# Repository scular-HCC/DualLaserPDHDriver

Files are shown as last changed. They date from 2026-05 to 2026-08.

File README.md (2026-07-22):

# Dual-Laser PDH Driver

**A precision two-channel controller for 1550 nm DFB butterfly lasers — a differential optical thermometer built as a 3U Eurocard instrument.**

Each channel provides low-noise constant-current laser drive, a bipolar linear TEC temperature controller, RF frequency modulation, and a synchronous-demodulation Pound–Drever–Hall lock that holds the laser to the side of an optical resonance. Lasers A and B lock to their own fringe of a shared reference cavity; the beat frequency between them, Δν = S·(T_B − T_A) with S ≈ 2 GHz/K, is a ratiometric measurement in which slow common-mode drift cancels.

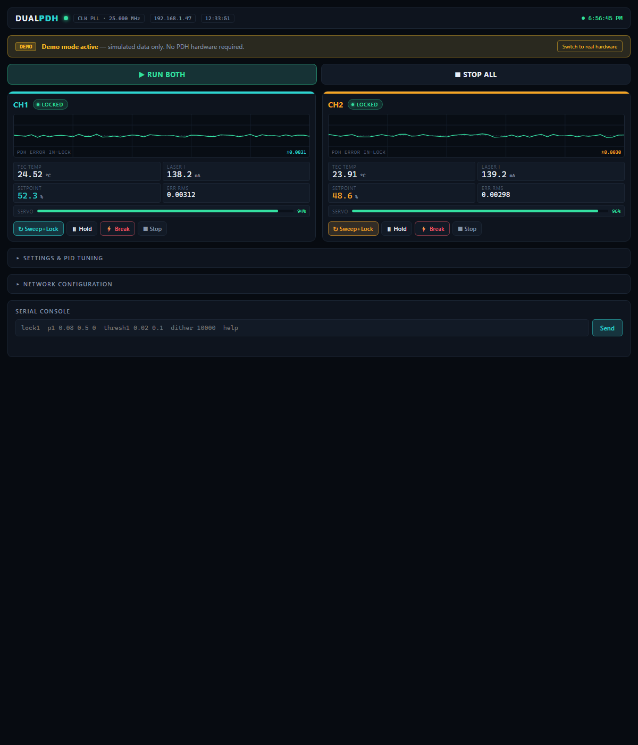
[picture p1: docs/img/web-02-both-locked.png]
Web dashboard — both channels locked


## Highlights

| | |
|---|---|
| **2×** | 1550 nm DFB laser channels |
| **≈2 GHz/K** | beat sensitivity |
| **4–40 nK** | 60 s stability (equivalent-kelvin Allan deviation) |
| **±2.5 A** | bipolar linear TEC per channel |
| **8-slot** | 3U passive backplane, card-based architecture |

The RF analog-derivative lock this hardware runs targets the ≈4–11 nK regime, limited primarily by the laser's residual amplitude modulation (RAM), not by the electronics.

## ⚠️ Safety

This is a mains-powered Class 3B/4 laser instrument. Before working on it, read [Section 02 of the User Manual](docs/laser_driver_v5_user_manual.html). In brief:

- **Mains voltage** — the AC board and toroidal transformers carry 120 VAC. Only qualified personnel should open the enclosure with power applied; do not defeat the IEC inlet fuse or SL22 inrush thermistor.
- **Invisible 1550 nm laser radiation** — can damage the retina. Never look into a fiber connector or butterfly output; cap unused fibers; follow your site's laser-safety procedures.
- **Laser reverse voltage** — the DFB die tolerates only ≈2 V reverse. The per-channel BAT46W Schottky clamp is mandatory; confirm polarity before first power-on.
- **Live heatsinks** — on the pm22V and pm6V supplies the pass-transistor tabs sit at the raw rail (up to ≈±28 V), not ground. Isolate or keep them clear.

## Architecture

The instrument is a set of interchangeable cards on a passive 3U backplane, each in a universal slot with on-card jumper addressing:

- **AC Board** — mains entry, IEC inlet, transformers
- **pm22V / pm6V / pm1p8V** — linear power supplies (±18 V, ±6 V TEC, low-voltage rails)
- **DIG card** — Teensy-based controller, web dashboard, fault handling
- **CH card ×2** — per-channel laser constant-current drive + bipolar TEC
- **AFE card** — analog detection / synchronous-demodulation front end

## Documentation

| Document | Contents |
|---|---|
| **[User Manual (v5)](docs/laser_driver_v5_user_manual.html)** | Full theory of operation, per-card reference, software, bring-up, uncertainty budget |
| [Firmware reference](docs/firmware_reference.html) | Teensy firmware, command set, lock state machine |
| [Power review](docs/laser_driver_v5_power_review.html) | Supply analysis |
| [Project summary](Dual-Laser_PDH_Driver_Summary.pdf) | One-document overview (PDF) |

> The HTML docs are styled pages — they render best via GitHub Pages or by opening the file locally. On GitHub the raw source is shown when clicked.

## Repository layout

This repository spans several design generations. **`Lasser_Driver_v5/` is the current, card-based design** that the User Manual describes. `Laser_Driver_v3/` and `Laser_Driver_v4/` are earlier monolithic/mains prototypes retained for reference. Firmware lives in `Teensy/`, and all documentation is in `docs/`.

## License

Copyright © 2026 Stefan Cular. All rights reserved. See [LICENSE](LICENSE).
This project is published for reference and viewing only; no reuse is permitted without written permission.

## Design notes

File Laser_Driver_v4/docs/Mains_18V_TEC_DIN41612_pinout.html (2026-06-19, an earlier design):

# Mains 18V TEC — DIN 41612 Connector Pinout DRAFT

Backplane connector J6 — proposed pin assignment. Subject to review; signal-side nets are largely recommendations not yet in the schematic.

BoardLaser_Driver_v4 / Mains_18V_TEC

ConnectorDIN 41612 Type M, 24 signal + 8 power

Board part (RA male)ERNI 374144-E

Backplane mate (vert. female)ERNI 294711-E

Power bladesP1–P8, ~10 A each

Signal contactsa/b/c × 13–20, ~2 A each

Date2026-06-19

StatusDraft pinout proposal

Scope assumption: custom backplane. If this card plugs into a standard bus (VME, etc.) the pinout is dictated by that standard and this proposal does not apply.

## 1 Power blades — P1–P8

10 A blades. Each supply is paired with an adjacent ground blade for a short return loop and current sharing (matters for the pulsed 5 A TEC). All nets below already exist on the board.

Pin | Net | Class | Current | Note
P1 | +6V_TEC | HighCurrent | 5 A pk | TEC + rail
P2 | GND | GND | — | return for P1
P3 | -6V_TEC | HighCurrent | 3 A | TEC − rail
P4 | GND | GND | — | return for P3 / TEC return capacity
P5 | +22V | RawDC | ~0.5 A | main analog raw bus → downstream regs
P6 | GND | GND | — | return for P5
P7 | -22V | RawDC | ~0.5 A | negative analog raw bus
P8 | GND | GND | — | return for P7

4 supplies + 4 grounds, fully interleaved (~40 A return capacity). Order blades physically so +6V_TEC/GND land nearest the TEC pass-transistor copper.

## 2 Signal field — 24 contacts (rows a / b / c, columns 13–20)

Middle row b = ground curtain; outer rows a and c carry monitoring/control and spares.

### Row b (b13–b20) — ground

b13–b20 = GND ×8 | GND | exists | shield / return between signal rows a and c

### Row a (a13–a20) — monitor / sense

Pin | Signal | Status | Purpose
a13 | PG_22V | add | rail-good, ±22V
a14 | PG_TEC | add | rail-good, ±6V TEC
a15 | EN / INH | add | enable / inhibit (sequencing)
a16 | HS_NTC | exists | heatsink thermistor sense
a17 | +22V_SENSE | add · optional¹ | remote sense
a18 | -22V_SENSE | add · optional¹ | remote sense
a19 | +6V_TEC_SENSE | add · optional¹ | remote sense
a20 | -6V_TEC_SENSE | add · optional¹ | remote sense

### Row c (c13–c20) — control / reference / spare

Pin | Signal | Status | Purpose
c13 | DGND | exists | reference / digital ground
c14 | Earth | exists · see² | chassis bond
c15 | SENSE_RTN | add · optional¹ | sense reference (GND at load)
c16 | TEC_IMON | add | TEC current monitor out
c17 | FAULT / OT | add | over-temp / fault flag
c18 | — | spare | reserved
c19 | — | spare | reserved
c20 | — | spare | reserved

## 3 Legend & notes

HighCurrent (2.5 mm) RawDC (1.0 mm) GND (0.6 mm) Signal Spare/reserved

exists = net already in the schematic · add = needs monitoring/control circuitry · optional = nice-to-have.

¹ Remote sense is optional here. ±22V feeds downstream regulators that re-regulate, so backplane IR drop mostly doesn't matter. Sense is more useful on ±6V_TEC (linear headroom). Keep for margining/monitoring, otherwise reclaim those pins as spares.

² Earth. Safety/chassis ground conventionally bonds through the rack frame (front panel + card guides), not a connector pin. Pin Earth on c14 only if your backplane distributes earth — otherwise free c14 as spare.

### Existing vs to-be-added

Only 7 nets exist today and are assignable now: +22V, -22V, +6V_TEC, -6V_TEC, GND, DGND, Earth. The PG_*, EN, HS_NTC readout, TEC_IMON, FAULT, and sense lines require circuitry to be added (the v3 rail-good / voltage-monitor blocks are a starting point).

Mains_18V_TEC DIN 41612 pinout — DRAFT, 2026-06-19. Connector ERNI 374144-E (board) / 294711-E (mate). Net classes per the imported v3 power-board scheme. This document is a proposal for review and does not yet reflect committed schematic nets.

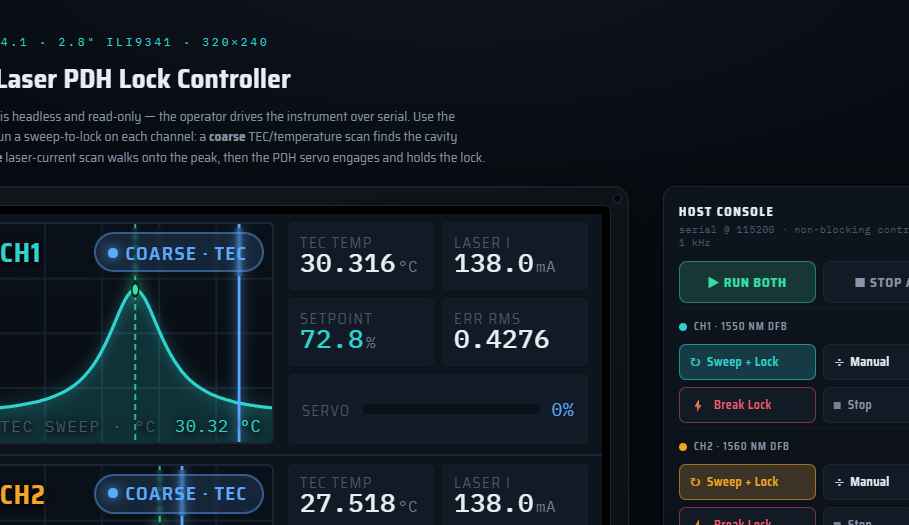
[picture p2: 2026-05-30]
docs/img/screen-standalone.png

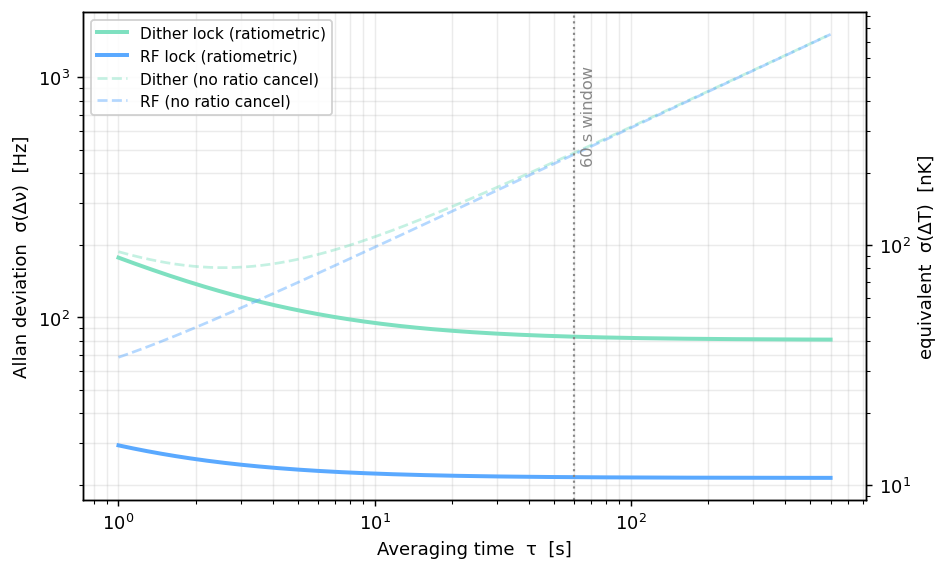
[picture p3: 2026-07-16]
docs/img/allan_uncertainty.png

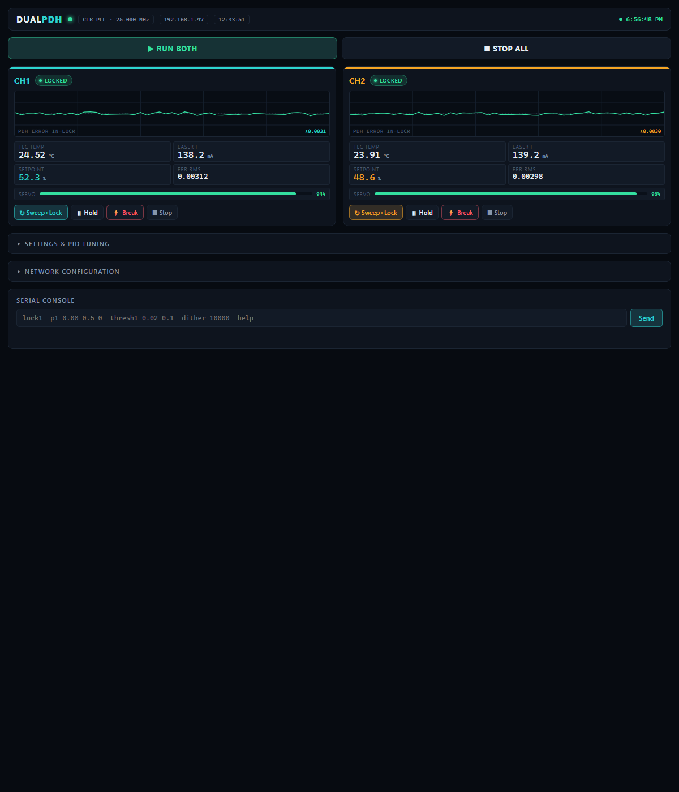
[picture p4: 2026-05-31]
docs/img/web-05-demo-off.png

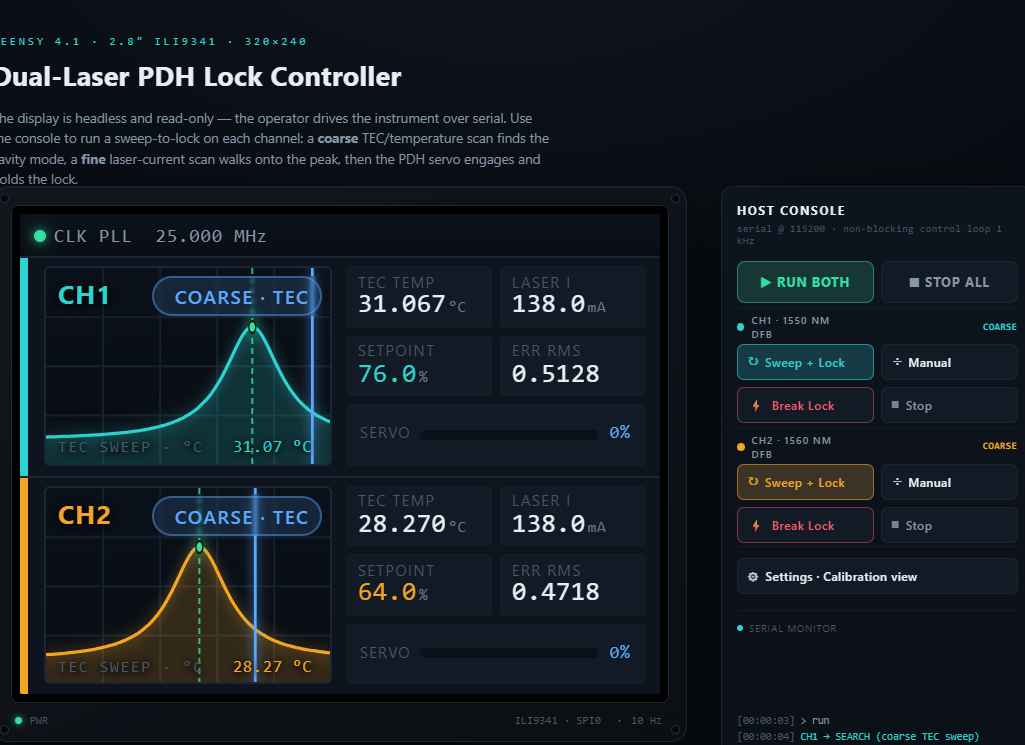
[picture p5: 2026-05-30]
docs/img/screen-final.png

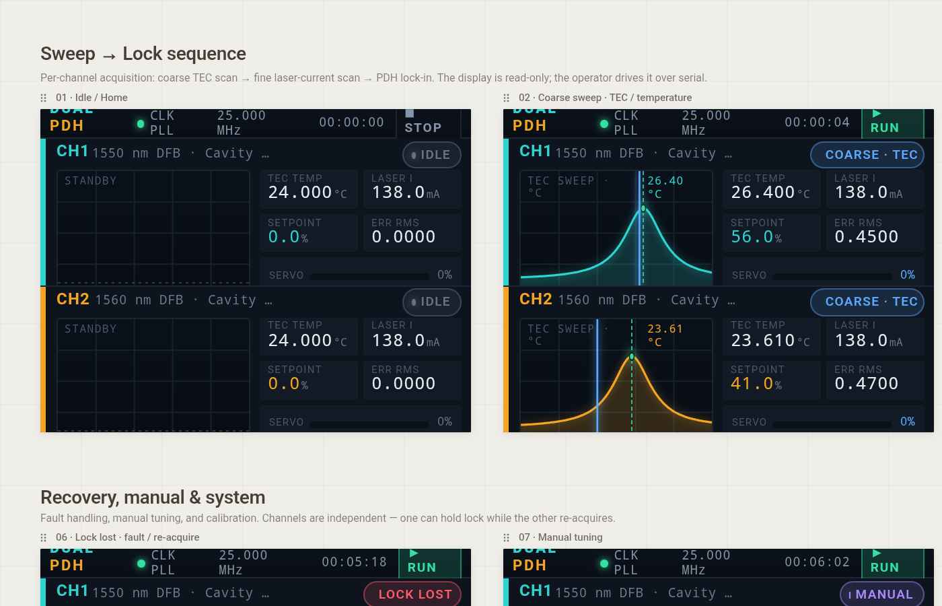
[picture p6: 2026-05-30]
docs/img/screen-board.png

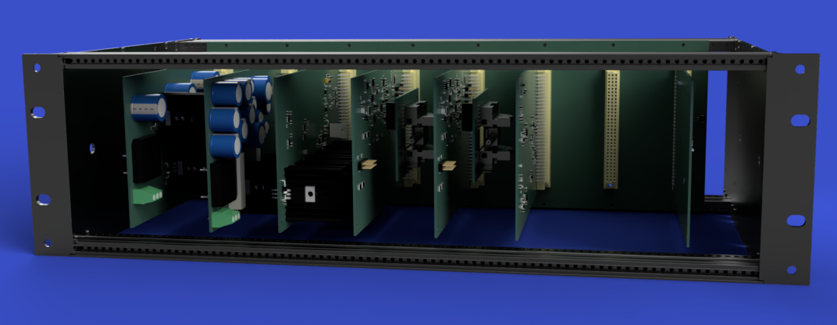
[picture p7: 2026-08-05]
docs/img/instrument-3d-render.png

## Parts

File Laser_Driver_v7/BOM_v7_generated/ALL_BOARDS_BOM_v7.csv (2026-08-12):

Quantity | Manufacturer Part Number | Manufacturer | Customer Reference | Value | Footprint
5 | 1729131 | Phoenix Contact | AC_Board:J1,AC_Board:J2,AC_Board:J3,pm22V:J5,pm6V:J4 | Screw_Terminal_01x03 | TerminalBlock_Phoenix_MKDS-1,5-3-5.08_1x03_P5.08mm_Horizontal
12 | CRCW08051K00FKEA | Vishay Dale | AC_Board:R1,pm6V:R38,pm6V:R39,pm1p8V_pm5V_5Vref_5Vlaser:R17,DIG_Card:R107,DIG_Card:R108,DIG_Card:R111,DIG_Card:VM_R51,CH_Card:R42,CH_Card:R55,AFE_Card:R125,AFE_Card:R128 | 1k | R_0805_2012Metric_Pad1.20x1.40mm_HandSolder
1 | SL2210005 | Ametherm | AC_Board:TH1 | Ametherm SL22 10005 | R_Axial_DIN0411_L9.9mm_D3.6mm_P7.62mm_Vertical
120 | CL21B104KBCNNNC | Samsung Electro-Mechanics | AFE_Card:C213,AFE_Card:C214,AFE_Card:C216,AFE_Card:C217,AFE_Card:C218,AFE_Card:C219,AFE_Card:C220,AFE_Card:C221,AFE_Card:C222,AFE_Card:C224,AFE_Card:C225,AFE_Card:C227,AFE_Card:C230,AFE_Card:C233,AFE_Card:C234,AFE_Card:C235,AFE_Card:C236,AFE_Card:C237,AFE_Card:C238,AFE_Card:C247,AFE_Card:C248,AFE_Card:C249,AFE_Card:C250,AFE_Card:C251,AFE_Card:C253,AFE_Card:C254,AFE_Card:C255,AFE_Card:C256,AFE_Card:C258,AFE_Card:C_K1,AFE_Card:C_K2,Backplane:C1,CH_Card:C116,CH_Card:C117,CH_Card:C118,CH_Card:C122,CH_Card:C123,CH_Card:C130,CH_Card:C131,CH_Card:C132,CH_Card:C133,CH_Card:C134,CH_Card:C135,CH_Card:C136,CH_Card:C137,CH_Card:C138,CH_Card:C139,CH_Card:C140,CH_Card:C141,CH_Card:C142,CH_Card:C143,CH_Card:C144,CH_Card:C145,CH_Card:C146,CH_Card:C147,CH_Card:C148,CH_Card:C149,CH_Card:C152,CH_Card:C153,CH_Card:C155,CH_Card:C156,CH_Card:C158,CH_Card:C161,CH_Card:C164,CH_Card:C165,CH_Card:C166,CH_Card:C167,CH_Card:C168,CH_Card:C169,CH_Card:C170,CH_Card:C171,CH_Card:C172,CH_Card:C173,CH_Card:C174,CH_Card:C176,CH_Card:C177,CH_Card:C65,CH_Card:C66,CH_Card:C_NTC1,DIG_Card:C301,DIG_Card:C302,DIG_Card:C305,DIG_Card:C306,DIG_Card:C307,DIG_Card:C312,DIG_Card:C314,DIG_Card:C315,DIG_Card:C316,DIG_Card:C317,DIG_Card:C324,DIG_Card:C80,DIG_Card:C81,DIG_Card:C82,DIG_Card:C84,DIG_Card:C85,DIG_Card:C86,DIG_Card:C88,DIG_Card:C92,DIG_Card:VM_C75,DIG_Card:VM_C76,DIG_Card:VM_C77,DIG_Card:VM_C78,DIG_Card:VM_C79,DIG_Card:VM_C80,DIG_Card:VM_C90,pm1p8V_pm5V_5Vref_5Vlaser:C10,pm1p8V_pm5V_5Vref_5Vlaser:C14,pm1p8V_pm5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 | 100n | C_0805_2012Metric_Pad1.18x1.45mm_HandSolder
1 | SMAJ5.0CA-E3/61 |  | Backplane:D3 | SMAJ5.0CA | D_SMA-SMB_Universal_Handsoldering
8 | 09032966855 | HARTING | Backplane:J1,Backplane:J2,Backplane:J3,Backplane:J4,Backplane:J5,Backplane:J6,Backplane:J7,Backplane:J8 | DIN41612_03x32_C_Split | DIN41612_C_3x32_Female_Vertical_THT
6 | RC0805JR-070RL | YAGEO | Backplane:R1,pm1p8V_pm5V_5Vref_5Vlaser:R11,DIG_Card:R314,DIG_Card:R315,CH_Card:R73,CH_Card:R74 | 0 | R_0805_2012Metric_Pad1.20x1.40mm_HandSolder
4 | CL21B474KBFNNNE | Samsung | pm22V:C1,pm22V:C2,pm6V:C42,pm6V:C43 | 470nF | C_0805_2012Metric_Pad1.18x1.45mm_HandSolder
6 | UVZ1H222MHD | Nichicon | pm22V:C3,pm22V:C4,pm22V:C9,pm22V:C10,pm6V:C46,pm6V:C47 | 2200uF 50V | CP_Radial_D18.0mm_P7.50mm
2 | UHE1H102MHD | Nichicon | pm22V:C5,pm22V:C6 | 1000uF 50V | CP_Radial_D16.0mm_P7.50mm
6 | CL21B225KBYNNWE | Samsung | pm22V:C7,pm22V:C8,pm6V:C44,pm6V:C45,pm6V:C52,pm6V:C53 | 2.2 uF | C_0805_2012Metric_Pad1.18x1.45mm_HandSolder
2 | GBPC1510W | Surge Components | pm22V:D1,pm6V:D7 | GBPC1510W | Diode_Bridge_28.6x28.6x7.3mm_P18.0mm_P11.6mm
4 | 1N4742ATR | onsemi | pm22V:D2,pm22V:D3,pm6V:D8,pm6V:D9 | 1N4742A | D_DO-41_SOD81_P10.16mm_Horizontal
10 | 531102B02500G | Boyd | pm22V:HS1,pm22V:HS2,pm6V:HS2,pm6V:HS3,pm1p8V_pm5V_5Vref_5Vlaser:HS1,pm1p8V_pm5V_5Vref_5Vlaser:HS2,pm1p8V_pm5V_5Vref_5Vlaser:HS3,pm1p8V_pm5V_5Vref_5Vlaser:HS4,pm1p8V_pm5V_5Vref_5Vlaser:HS5,pm1p8V_pm5V_5Vref_5Vlaser:HS6 | Heatsink Boyd 531102B02500G | Heatsink_AAVID_Extruded_531102B02500G_34.9x12.7mm_H38.1mm
2 | 6223BG | Boyd | pm22V:HS3,pm6V:HS1 | Heatsink Boyd 6223BG (GBPC) | Bridge_GBPC_Heatsink_Boyd_6223BG
6 | 09031966921 | HARTING | pm22V:J6,pm6V:J6,pm1p8V_pm5V_5Vref_5Vlaser:J6,DIG_Card:J301,CH_Card:J1,AFE_Card:J1 | DIN41612_03x32_C_Split | DIN41612_C_3x32_Male_Horizontal_THT
1 | IRF540NPBF | Infineon | pm22V:Q1 | IRF540NPBF | TO-220-3_Vertical
4 | IRF9540NPBF | Infineon | pm22V:Q2,pm6V:Q4,CH_Card:Q14,CH_Card:Q18 | IRF9540NPBF | TO-220-3_Vertical
4 | TUW15J15RE | Ohmite | pm22V:R2,pm22V:R3,pm6V:R20,pm6V:R21 | 15 | R_Axial_Power_L38.0mm_W9.0mm_P45.72mm
5 | RC0805FR-071ML | Yageo | pm22V:R4,pm22V:R5,pm6V:R26,pm6V:R27,DIG_Card:R105 | 1M | R_0805_2012Metric_Pad1.20x1.40mm_HandSolder
8 | ERA-6AEB104V | Panasonic | pm22V:R6,pm22V:R7,pm6V:R22,pm6V:R23,DIG_Card:R109,CH_Card:R78,AFE_Card:R146,AFE_Card:R147 | 100k | R_0805_2012Metric_Pad1.20x1.40mm_HandSolder
2 | CRL1206-FW-R470ELF | Bourns | pm22V:R8,pm22V:R9 | 0.47 | R_1206_3216Metric_Pad1.30x1.75mm_HandSolder
6 | UHE1E332MHD | Nichicon | pm6V:C34,pm6V:C35,pm6V:C36,pm6V:C37,pm6V:C38,pm6V:C39 | 3300uF (UPW1E332MHD) | CP_Radial_D16.0mm_P7.50mm
6 | UHE1E102MPD | Nichicon | pm6V:C40,pm6V:C41,pm6V:C48,pm6V:C49,pm6V:C50,pm6V:C51 | 1000uF 25V | CP_Radial_D12.5mm_P5.00mm
4 | 1N4148W-7-F | Diodes Incorporated | pm6V:D10,pm6V:D11,pm6V:D_CP1,pm6V:D_CP2 | 1N4148W | D_SOD-123
1 | IRF540ZPBF | Infineon | pm6V:Q3 | IRF540ZPBF | TO-220-3_Vertical
1 | MMBT2907A-TP | MCC | pm6V:Q5 | MMBT2907 | SOT-23_Handsoldering
1 | MMBT2222ALT1G | onsemi | pm6V:Q6 | MMBT2222 | SOT-23_Handsoldering
2 | MJL21193G | onsemi | pm6V:Q7,pm6V:Q8 | Q_PNP_MJL21193 | TO-264-3_Vertical_HS657-10ABPE
2 | MJL21194G | onsemi | pm6V:Q9,pm6V:Q10 | Q_NPN MJL21194 | TO-264-3_Vertical_HS657-10ABPE
2 | ERJ-6ENF6042V | Panasonic | pm6V:R24,pm6V:R31 | 60.4k | R_0805_2012Metric_Pad1.20x1.40mm_HandSolder
2 | ERA-6AEB153V | Panasonic | pm6V:R25,pm6V:R30 | 15k | R_0805_2012Metric_Pad1.20x1.40mm_HandSolder
2 | ERA-6AEB152V | Panasonic | pm6V:R28,pm6V:R29 | 1.5k Bias | R_0805_2012Metric_Pad1.20x1.40mm_HandSolder
6 | WSL2512R1000FEA | Vishay Dale | pm6V:R34,pm6V:R35,pm6V:R36,pm6V:R37,CH_Card:R63,CH_Card:R65 | 0.1R | R_2512_6332Metric_Pad1.40x3.35mm_HandSolder
9 | RC0805FR-0710RL | YAGEO | pm6V:R40,pm6V:R41,pm6V:R42,pm6V:R43,CH_Card:R48,CH_Card:R116,CH_Card:R126,CH_Card:R132,AFE_Card:R216 | 10R base-stopper | R_0805_2012Metric_Pad1.20x1.40mm_HandSolder
2 | LM4051AIM3-ADJ/NOPB | Texas Instruments | pm6V:U11,pm6V:U12 | LM4051AIM3-ADJ/NOPB | SOT-23_Handsoldering
10 | CL21B475KAFNNNE | Samsung Electro-Mechanics | pm1p8V_pm5V_5Vref_5Vlaser:C11,pm1p8V_pm5V_5Vref_5Vlaser:C12,pm1p8V_pm5V_5Vref_5Vlaser:C20,pm1p8V_pm5V_5Vref_5Vlaser:C21,pm1p8V_pm5V_5Vref_5Vlaser:C30,pm1p8V_pm5V_5Vref_5Vlaser:C31,pm1p8V_pm5V_5Vref_5Vlaser:C56,pm1p8V_pm5V_5Vref_5Vlaser:C60,pm1p8V_pm5V_5Vref_5Vlaser:C67,pm1p8V_pm5V_5Vref_5Vlaser:C70 | 4.7uF | C_0805_2012Metric_Pad1.18x1.45mm_HandSolder
29 | C0805C106K3PACTU | KEMET | pm1p8V_pm5V_5Vref_5Vlaser:C15,pm1p8V_pm5V_5Vref_5Vlaser:C22,pm1p8V_pm5V_5Vref_5Vlaser:C28,pm1p8V_pm5V_5Vref_5Vlaser:C29,pm1p8V_pm5V_5Vref_5Vlaser:C65,pm1p8V_pm5V_5Vref_5Vlaser:C66,pm1p8V_pm5V_5Vref_5Vlaser:C68,DIG_Card:C322,DIG_Card:C323,DIG_Card:C325,CH_Card:C115,CH_Card:C121,CH_Card:C150,CH_Card:C151,CH_Card:C154,CH_Card:C157,CH_Card:C160,CH_Card:C163,AFE_Card:C215,AFE_Card:C223,AFE_Card:C226,AFE_Card:C228,AFE_Card:C229,AFE_Card:C231,AFE_Card:C232,AFE_Card:C242,AFE_Card:C243,AFE_Card:C252,AFE_Card:C257 | 10uF | C_0805_2012Metric_Pad1.18x1.45mm_HandSolder
1 | T520B106M016ATE100 | KEMET | pm1p8V_pm5V_5Vref_5Vlaser:C16 | 10uF 16V Polymer | CP_EIA-3528-21_Kemet-B_HandSolder
1 | TMK325ABJ476MM-P | Taiyo Yuden | pm1p8V_pm5V_5Vref_5Vlaser:C19 | 47uF RC | C_1210_3225Metric_Pad1.33x2.70mm_HandSolder
6 | C0805C105K5RACTU | KEMET | pm1p8V_pm5V_5Vref_5Vlaser:C23,pm1p8V_pm5V_5Vref_5Vlaser:C24,pm1p8V_pm5V_5Vref_5Vlaser:C75,CH_Card:C113,CH_Card:C114,AFE_Card:C241 | 1uF | C_0805_2012Metric_Pad1.18x1.45mm_HandSolder
3 | CL21B334KBFNNNE | Samsung Electro-Mechanics | pm1p8V_pm5V_5Vref_5Vlaser:C57,pm1p8V_pm5V_5Vref_5Vlaser:C63,pm1p8V_pm5V_5Vref_5Vlaser:C64 | 0.33uF | C_0805_2012Metric_Pad1.18x1.45mm_HandSolder
3 | 1210YD107MAT2A | KYOCERA AVX | pm1p8V_pm5V_5Vref_5Vlaser:C59,CH_Card:C159,CH_Card:C162 | 100uF | C_1210_3225Metric_Pad1.33x2.70mm_HandSolder
7 | 1N4007RLG | onsemi | pm1p8V_pm5V_5Vref_5Vlaser:D4,pm1p8V_pm5V_5Vref_5Vlaser:D5,pm1p8V_pm5V_5Vref_5Vlaser:D6,pm1p8V_pm5V_5Vref_5Vlaser:D12,pm1p8V_pm5V_5Vref_5Vlaser:D13,pm1p8V_pm5V_5Vref_5Vlaser:D14,pm1p8V_pm5V_5Vref_5Vlaser:D15 | 1N4007 | D_DO-41_SOD81_P12.70mm_Horizontal
1 | ERA-6AEB6042V | Panasonic Industry | pm1p8V_pm5V_5Vref_5Vlaser:R10 | 60.4k 0.1% | R_0805_2012Metric_Pad1.20x1.40mm_HandSolder
1 | RC1206FR-074R7L | YAGEO | pm1p8V_pm5V_5Vref_5Vlaser:R12 | 4.7R | R_1206_3216Metric_Pad1.30x1.75mm_HandSolder
1 | ERA-6AEB3322V | Panasonic Industry | pm1p8V_pm5V_5Vref_5Vlaser:R13 | 33.2k 0.1% | R_0805_2012Metric_Pad1.20x1.40mm_HandSolder
1 | ERA-6AEB1272V | Panasonic Industry | pm1p8V_pm5V_5Vref_5Vlaser:R14 | 12.7k 0.1% | R_0805_2012Metric_Pad1.20x1.40mm_HandSolder
1 | ERA-6AEB1373V | Panasonic Industry | pm1p8V_pm5V_5Vref_5Vlaser:R15 | 137k 0.1% | R_0805_2012Metric_Pad1.20x1.40mm_HandSolder
9 | ERA-6AEB103V | Panasonic Industry | pm1p8V_pm5V_5Vref_5Vlaser:R16,pm1p8V_pm5V_5Vref_5Vlaser:R48,pm1p8V_pm5V_5Vref_5Vlaser:R49,CH_Card:R_NTC1,CH_Card:R130,CH_Card:R131,CH_Card:R133,CH_Card:R_f1,CH_Card:R_f2 | 10k 0.1% | R_0805_2012Metric_Pad1.20x1.40mm_HandSolder
2 | RT0805BRD07143KL | YAGEO | pm1p8V_pm5V_5Vref_5Vlaser:R18,pm1p8V_pm5V_5Vref_5Vlaser:R19 | 143k 0.1% | R_0805_2012Metric_Pad1.20x1.40mm_HandSolder
1 | RC1206FR-071RL | YAGEO | pm1p8V_pm5V_5Vref_5Vlaser:R40 | 1R RC | R_1206_3216Metric_Pad1.30x1.75mm_HandSolder
1 | ERA-6AEB2492V | Panasonic Industry | pm1p8V_pm5V_5Vref_5Vlaser:R41 | 24.9k 0.1% | R_0805_2012Metric_Pad1.20x1.40mm_HandSolder
2 | ERJ-6BWFR020V | Panasonic Industry | pm1p8V_pm5V_5Vref_5Vlaser:R42,pm1p8V_pm5V_5Vref_5Vlaser:R43 | 20m 1% | R_0805_2012Metric_Pad1.20x1.40mm_HandSolder
1 | ERA-6AEB6040V | Panasonic | pm1p8V_pm5V_5Vref_5Vlaser:R44 | 604 | R_0805_2012Metric_Pad1.20x1.40mm_HandSolder
6 | ERA-6AEB4992V | Panasonic Industry | pm1p8V_pm5V_5Vref_5Vlaser:R45,pm1p8V_pm5V_5Vref_5Vlaser:R46,AFE_Card:R138,AFE_Card:R139,AFE_Card:R140,AFE_Card:R142 | 49.9k 0.1% | R_0805_2012Metric_Pad1.20x1.40mm_HandSolder
1 | ERA-6AEB163V | Panasonic | pm1p8V_pm5V_5Vref_5Vlaser:R47 | 16k | R_0805_2012Metric_Pad1.20x1.40mm_HandSolder
1 | ERJ-6ENF49R9V | Panasonic Industry | pm1p8V_pm5V_5Vref_5Vlaser:R50 | 49.9R | R_0805_2012Metric_Pad1.20x1.40mm_HandSolder
3 | MC7808CTG | onsemi | pm1p8V_pm5V_5Vref_5Vlaser:U1,pm1p8V_pm5V_5Vref_5Vlaser:U14,pm1p8V_pm5V_5Vref_5Vlaser:U17 | MC7808CTG | TO-220-3_Vertical
3 | LT3042EMSE#PBF | Analog Devices Inc. | pm1p8V_pm5V_5Vref_5Vlaser:U2,pm1p8V_pm5V_5Vref_5Vlaser:U10,AFE_Card:U1 | LT3042EMSE +5.5V | MSOP-10-1EP_3x3mm_P0.5mm_EP1.68x1.88mm
1 | LTC6655BHMS8-5#PBF | Analog Devices Inc. | pm1p8V_pm5V_5Vref_5Vlaser:U3 | LTC6655BHMS8-5#PBF | MSOP-8_3x3mm_P0.65mm
2 | MC7812CTG | onsemi | pm1p8V_pm5V_5Vref_5Vlaser:U4,pm1p8V_pm5V_5Vref_5Vlaser:U13 | MC7812CTG | TO-220-3_Vertical
1 | MC7805CTG | onsemi | pm1p8V_pm5V_5Vref_5Vlaser:U5 | MC7805CTG | TO-220-3_Vertical
4 | LT3045EMSE#PBF | Analog Devices Inc. | pm1p8V_pm5V_5Vref_5Vlaser:U6,pm1p8V_pm5V_5Vref_5Vlaser:U15,pm1p8V_pm5V_5Vref_5Vlaser:U16,pm1p8V_pm5V_5Vref_5Vlaser:U19 | LT3045EMSE 3.3V | MSOP-12-1EP_3x4.039mm_P0.65mm_EP1.651x2.845mm
1 | LP5907MFX-1.8/NOPB | Texas Instruments | pm1p8V_pm5V_5Vref_5Vlaser:U7 | LP5907MFX-1.8 | SOT-23-5
1 | TPS7A3901DSCR | Texas Instruments | pm1p8V_pm5V_5Vref_5Vlaser:U8 | TPS7A3901DSCR | Texas_DSC0010J_ThermalVias
2 | LT3094EMSE#PBF | Analog Devices Inc. | pm1p8V_pm5V_5Vref_5Vlaser:U9,pm1p8V_pm5V_5Vref_5Vlaser:U20 | LT3094EMSE -14.3V | MSOP-12-1EP_3x4.039mm_P0.65mm_EP1.651x2.845mm
1 | MC7906CTG | onsemi | pm1p8V_pm5V_5Vref_5Vlaser:U18 | MC7906CTG | TO-220-3_Vertical
10 | OPA192IDBVR | Texas Instruments | pm1p8V_pm5V_5Vref_5Vlaser:U21,DIG_Card:U301,DIG_Card:U302,CH_Card:U17,CH_Card:U19,CH_Card:U22,CH_Card:U24,CH_Card:U106,AFE_Card:U202,AFE_Card:U203 | OPA192IDBVR | SOT-23-5_HandSoldering
1 | DEV-16771 | SparkFun | DIG_Card:A1 | TEENSY_4.1 | TEENSY_LONG_EXT
21 | CL21B103KBANNNC | Samsung Electro-Mechanics | DIG_Card:C83,DIG_Card:C87,DIG_Card:C89,DIG_Card:C90,DIG_Card:C91,DIG_Card:C320,DIG_Card:C321,DIG_Card:VM_C81,DIG_Card:VM_C82,DIG_Card:VM_C83,DIG_Card:VM_C84,DIG_Card:VM_C85,DIG_Card:VM_C86,DIG_Card:VM_C87,DIG_Card:VM_C88,DIG_Card:VM_C89,CH_Card:C119,CH_Card:C120,CH_Card:C175,AFE_Card:C94,AFE_Card:C95 | 10n | C_0805_2012Metric_Pad1.18x1.45mm_HandSolder
4 | CL21B102KBANNNC | Samsung Electro-Mechanics | DIG_Card:C303,DIG_Card:C304,AFE_Card:C96,AFE_Card:C97 | 1n ERR1 ADC filter | C_0805_2012Metric
2 | CC0805KKX7R8BB105 | YAGEO | DIG_Card:C313,DIG_Card:C319 | 1uF Y1 3V3_OSC | C_0805_2012Metric
1 | CC0805KKX5R7BB106 | YAGEO | DIG_Card:C318 | 10uF U42 3V3 | C_0805_2012Metric
1 | BAV99-7-F | Diodes Incorporated | DIG_Card:D24 | BAV99 | SOT-23
2 | BAT54S-7-F | Diodes Incorporated | DIG_Card:D301,DIG_Card:D302 | BAT54S ERR1 ADC clamp | SOT-23
9 | BAT54WS-7-F | Diodes Incorporated | DIG_Card:D303,DIG_Card:D304,DIG_Card:D305,DIG_Card:D306,DIG_Card:D307,DIG_Card:D308,DIG_Card:D309,DIG_Card:D310,DIG_Card:D311 | BAT54WS VM fault OR | D_SOD-323
2 | MPZ2012S601AT000 | TDK | DIG_Card:FB301,DIG_Card:FB302 | 600R@100MHz FB Y1 | L_0805_2012Metric
2 | ACX1234-ND | (DigiKey PN) | DIG_Card:J2,DIG_Card:J302 | 10MHz Ref SMA | SMA_BAT_Wireless_BWSMA-KWE-Z001
1 | BWSMA-KWE-Z001 | BAT Wireless | DIG_Card:J302B1 | LO2 out SMA | SMA_BAT_Wireless_BWSMA-KWE-Z001
3 | RC0805FR-0749R9L | YAGEO | DIG_Card:R104,DIG_Card:R312,DIG_Card:R313 | 49R9 10MHz ref term | R_0805_2012Metric_Pad1.20x1.40mm_HandSolder
1 | ERA-6AEB273V | Panasonic | DIG_Card:R106 | 27k | R_0805_2012Metric_Pad1.20x1.40mm_HandSolder
1 | RC0805FR-0710ML | YAGEO | DIG_Card:R110 | 10M | R_0805_2012Metric_Pad1.20x1.40mm_HandSolder
2 | ERA-6AEB222V | Panasonic | DIG_Card:R112,DIG_Card:R113 | 2.2k | R_0805_2012Metric_Pad1.20x1.40mm_HandSolder
14 | RC0805FR-07100RL | YAGEO | DIG_Card:R114,DIG_Card:R301,DIG_Card:R302,DIG_Card:VM_R56,DIG_Card:VM_R66,DIG_Card:VM_R72,CH_Card:R111,CH_Card:R112,CH_Card:R113,CH_Card:R114,AFE_Card:R211,AFE_Card:R212,AFE_Card:R_S1,AFE_Card:R_S2 | 100 | R_0805_2012Metric_Pad1.20x1.40mm_HandSolder
4 | RC0805FR-073K3L | YAGEO | DIG_Card:R303,DIG_Card:R304,AFE_Card:R116,AFE_Card:R117 | 3k3 ERR1 ADC series | R_0805_2012Metric
42 | RC0805FR-0710KL | YAGEO | DIG_Card:R305,DIG_Card:VM_R54,DIG_Card:VM_R55,DIG_Card:VM_R58,DIG_Card:VM_R60,DIG_Card:VM_R62,DIG_Card:VM_R63,DIG_Card:VM_R67,DIG_Card:VM_R69,DIG_Card:VM_R70,DIG_Card:VM_R73,DIG_Card:VM_R75,DIG_Card:VM_R76,DIG_Card:VM_R79,DIG_Card:VM_R80,DIG_Card:VM_R81,DIG_Card:VM_R82,DIG_Card:VM_R84,DIG_Card:VM_R85,DIG_Card:VM_R86,DIG_Card:VM_R87,CH_Card:R79,CH_Card:R92,CH_Card:R115,CH_Card:R120,CH_Card:R121,CH_Card:R122,CH_Card:R123,CH_Card:R124,CH_Card:R125,CH_Card:R127,AFE_Card:R120,AFE_Card:R121,AFE_Card:R122,AFE_Card:R123,AFE_Card:R126,AFE_Card:R129,AFE_Card:R134,AFE_Card:R135,AFE_Card:R145,AFE_Card:R213,AFE_Card:R214 | 10k FAULT_n pullup | R_0805_2012Metric
7 | RC0805FR-0747RL | YAGEO | DIG_Card:R306,DIG_Card:R307,CH_Card:R69,CH_Card:R70,CH_Card:R75,AFE_Card:R217,AFE_Card:R218 | 47R MOD1 bus series | R_0805_2012Metric
4 | RC0805FR-0733RL | YAGEO | DIG_Card:R311,DIG_Card:R316,DIG_Card:R317,DIG_Card:R318 | 33R CLK10M series | R_0805_2012Metric
4 | AD9833BRMZ | Analog Devices | DIG_Card:U34,DIG_Card:U35,DIG_Card:U38,DIG_Card:U39 | AD9833xRM | MSOP-10_3x3mm_P0.5mm
1 | LMV7219M5/NOPB | Texas Instruments | DIG_Card:U40 | LMV7219M5 | SOT-23-5
1 | SN74LVC1G3157DBVR | Texas Instruments | DIG_Card:U41 | SN74LVC1G3157DBVR | SOT-23-6_Handsoldering
1 | CDCE913PWR | Texas Instruments | DIG_Card:U42 | CDCE913PWG4 | SOP65P640X120-14N
1 | COM-28379 | SparkFun | DIG_Card:U44 | CR2013-MI2120 | CR2013-MI2120
1 | SN74LVC1G125DBVR | Texas Instruments | DIG_Card:U303 | 74LVC1G125 CLK10M bus buffer | SOT-23-5
9 | 150080GS75000 | Würth Elektronik | DIG_Card:VM_D16,DIG_Card:VM_D17,DIG_Card:VM_D18,DIG_Card:VM_D19,DIG_Card:VM_D20,DIG_Card:VM_D21,DIG_Card:VM_D22,DIG_Card:VM_D23,DIG_Card:VM_D24 | +15V_OK | LED_0805_2012Metric_Pad1.15x1.40mm_HandSolder
9 | MMBT3904-7-F | Diodes Inc | DIG_Card:VM_Q11,DIG_Card:VM_Q12,DIG_Card:VM_Q13,DIG_Card:VM_Q14,DIG_Card:VM_Q15,DIG_Card:VM_Q16,DIG_Card:VM_Q17,DIG_Card:VM_Q18,DIG_Card:VM_Q19 | MMBT3904 | SOT-23
1 | ERA-6AEB2942V | Panasonic | DIG_Card:VM_R50 | 29.4k | R_0805_2012Metric_Pad1.20x1.40mm_HandSolder
1 | ERA-6AEB9531V | Panasonic | DIG_Card:VM_R52 | 9.53k | R_0805_2012Metric_Pad1.20x1.40mm_HandSolder
1 | ERA-6AEB114V | Panasonic | DIG_Card:VM_R53 | 110k | R_0805_2012Metric_Pad1.20x1.40mm_HandSolder
2 | ERA-6AEB124V | Panasonic | DIG_Card:VM_R59,AFE_Card:R2 | 120k | R_0805_2012Metric_Pad1.20x1.40mm_HandSolder
1 | RC0805FR-0740K2L | YAGEO | DIG_Card:VM_R61 | 40.2k | R_0805_2012Metric_Pad1.20x1.40mm_HandSolder
1 | ERA-6AEB4752V | Panasonic | DIG_Card:VM_R64 | 47.5k | R_0805_2012Metric_Pad1.20x1.40mm_HandSolder
2 | ERA-6AEB3012V | Panasonic | DIG_Card:VM_R65,DIG_Card:VM_R77 | 30.1k | R_0805_2012Metric_Pad1.20x1.40mm_HandSolder
1 | ERA-6AEB3832V | Panasonic | DIG_Card:VM_R71 | 38.3k | R_0805_2012Metric_Pad1.20x1.40mm_HandSolder
1 | ERA-6AEB1652V | Panasonic | DIG_Card:VM_R78 | 16.5k | R_0805_2012Metric_Pad1.20x1.40mm_HandSolder
1 | ERA-6AEB4421V | Panasonic | DIG_Card:VM_R83 | 4.42k | R_0805_2012Metric_Pad1.20x1.40mm_HandSolder
9 | RC0805FR-071K3L | YAGEO | DIG_Card:VM_R88,DIG_Card:VM_R89,DIG_Card:VM_R90,DIG_Card:VM_R91,DIG_Card:VM_R92,DIG_Card:VM_R93,DIG_Card:VM_R94,DIG_Card:VM_R95,DIG_Card:VM_R96 | 1.3k | R_0805_2012Metric_Pad1.20x1.40mm_HandSolder
9 | ERA-6AEB472V | Panasonic | DIG_Card:VM_R97,DIG_Card:VM_R98,DIG_Card:VM_R99,DIG_Card:VM_R100,DIG_Card:VM_R101,DIG_Card:VM_R102,DIG_Card:VM_R103,DIG_Card:VM_R104,DIG_Card:VM_R105 | 4.7k | R_0805_2012Metric_Pad1.20x1.40mm_HandSolder
1 | MCP6002-E/SN | Microchip | DIG_Card:VM_U22 | MCP6002-xSN | SOIC-8_3.9x4.9mm_P1.27mm
5 | LM339BIDR | Texas Instruments | DIG_Card:VM_U23,DIG_Card:VM_U25,DIG_Card:VM_U26,DIG_Card:VM_U27,DIG_Card:VM_U28 | LM339B | SOIC-14_3.9x8.7mm_P1.27mm
1 | MCP6004-E/SL | Microchip | DIG_Card:VM_U24 | MCP6004 | SOIC-14_3.9x8.7mm_P1.27mm
1 | ASE-10.000MHZ-LC-T | Abracon | DIG_Card:Y1 | ASE-10.000MHZ-LC-T | XTAL_ASE-10.000MHZ-LC-T
1 | CL21C101JBANNNC | Samsung Electro-Mechanics | CH_Card:C68 | 100pF NP0 | C_0805_2012Metric_Pad1.18x1.45mm_HandSolder
2 | GRM1555C1H2R2CA01D | Murata Electronics | CH_Card:C_f1,CH_Card:C_f2 | 2.2pF Cf | C_0402_1005Metric
4 | MMSZ4702T1G | onsemi | CH_Card:D16,CH_Card:D17,CH_Card:D20,CH_Card:D21 | MMSZ4702 15V | D_SOD-123
2 | BAT46W-7-F | Diodes Inc | CH_Card:D22,CH_Card:D23 | BAT46W rev prot | D_SOD-123
2 | 61300211121 | Wurth Elektronik | CH_Card:JP101,BTF_Card:JP1 | GA0 addr jumper | PinHeader_1x02_P2.54mm_Vertical
1 | TSW-107-21-G-D | Samtec | CH_Card:J_BTF1 | Butterfly daughter-card stacking header - Samtec TSW-107-21-G-D (30.99mm post) | BTF_Card_Mezzanine_2x07_M3
1 | B82432T1103K000 | TDK | CH_Card:L1 | 10u (SRF>>20MHz) | L_1812_4532Metric_Pad1.30x3.40mm_HandSolder
2 | IRL540NPBF | Infineon Technologies | CH_Card:Q13,CH_Card:Q17 | IRL540N | TO-220-3_Vertical_HS657-10ABPE
1 | DMN3404LQ-7 | Diodes Incorporated | CH_Card:Q19 | DMN3404L | SOT-23
1 | RC0805FR-073K16L | YAGEO | CH_Card:R41 | 3.16k | R_0805_2012Metric_Pad1.20x1.40mm_HandSolder
3 | ERA-6AEB203V | Panasonic Industry | CH_Card:R43,CH_Card:R45,CH_Card:R_bias1 | 20k 0.1% TEC_scaler_bot | R_0805_2012Metric
1 | ERA-6AEB4991V | Panasonic | CH_Card:R44 | 4.99k 0.1% TEC_scaler_top | R_0805_2012Metric
1 | ERA-6AEB333V | Panasonic | CH_Card:R49 | 33k flag pulldown | R_0805_2012Metric_Pad1.20x1.40mm_HandSolder
4 | ERA-6AEB471V | Panasonic | CH_Card:R56,CH_Card:R57,CH_Card:R58,CH_Card:R59 | 470R gate | R_0805_2012Metric_Pad1.20x1.40mm_HandSolder
1 | ERA-6AEB204V | Panasonic Industry | CH_Card:R66 | 200k 0.1% scaler_top | R_0805_2012Metric
1 | ERA-6AEB9090V | Panasonic Industry | CH_Card:R67 | 909R 0.1% scaler_bot | R_0805_2012Metric
2 | WSL2512R0100FEA | Vishay Dale | CH_Card:R68,CH_Card:R76 | 10mR link (was 47R - TEC path) | R_2512_6332Metric
4 | ERA-6AEB202V | Panasonic | CH_Card:R77,CH_Card:R117,AFE_Card:R124,AFE_Card:R127 | 2k (trim) | R_0805_2012Metric_Pad1.20x1.40mm_HandSolder
1 | WSL2512R2500FEA | Vishay Dale | CH_Card:R81 | 0.25R 1W | R_2512_6332Metric
1 | CRCW25124R70FKEG | Vishay Dale | CH_Card:R86 | 4R7 inrush limit | R_2512_6332Metric
1 | ERA-6AEB102V | Panasonic | CH_Card:R94 | Rp 1k | R_0805_2012Metric_Pad1.20x1.40mm_HandSolder
1 | RC0805FR-077M5L | YAGEO | CH_Card:R96 | Rsum 7.5M | R_0805_2012Metric_Pad1.20x1.40mm_HandSolder
1 | ERA-6AEB4870V | Panasonic | CH_Card:R98 | 487R | R_0805_2012Metric_Pad1.20x1.40mm_HandSolder
3 | ERA-6AEB8061V | Panasonic | CH_Card:R102,AFE_Card:R100,AFE_Card:R101 | 8.06k | R_0805_2012Metric_Pad1.20x1.40mm_HandSolder
2 | RC0805FR-074K99L | YAGEO | CH_Card:R118,CH_Card:R119 | 4.99k ADC prot | R_0805_2012Metric_Pad1.20x1.40mm_HandSolder
1 | HVCB0805FDC15M0 | Stackpole Electronics | CH_Card:R134 | 15M pedestal cancel | R_0805_2012Metric_Pad1.20x1.40mm_HandSolder
2 | OPA551UA | Texas Instruments | CH_Card:U21,CH_Card:U107 | OPA551U | SOIC-8_3.9x4.9mm_P1.27mm
4 | ADG419BRMZ | Analog Devices Inc. | CH_Card:U26,CH_Card:U104,CH_Card:U105,CH_Card:U108 | ADG419BRM | MSOP-8_3x3mm_P0.65mm
2 | INA828ID | Texas Instruments | CH_Card:U28,CH_Card:U32 | INA828 | SOIC-8_3.9x4.9mm_P1.27mm
2 | AD5696RARUZ | Analog Devices | CH_Card:U101,AFE_Card:U206 | AD5696R | TSSOP-16_4.4x5mm_P0.65mm
2 | ADS1115IDGSR | Texas Instruments | CH_Card:U102,AFE_Card:U201 | ADS1115 | MSOP-10_3x3mm_P0.5mm
1 | PCA9538PW,118 | NXP USA Inc. | CH_Card:U103 | PCA9538 | TSSOP-16_4.4x5mm_P0.65mm
2 | OPA380AID | Texas Instruments | CH_Card:U_TIA1,CH_Card:U_TIA2 | OPA380AIDR MPD | SOIC-8_3.9x4.9mm_P1.27mm
2 | C0805C475K3RACTU | Kemet | AFE_Card:C1,AFE_Card:C2 | 4.7uF X7R | C_0805_2012Metric_Pad1.18x1.45mm_HandSolder
2 | C0402C109C5GACTU | KEMET | AFE_Card:C78,AFE_Card:C79 | Cf 1p C0G 0402 | C_0402_1005Metric_Pad0.74x0.62mm_HandSolder
2 | C0805C680J5GACTU | Kemet | AFE_Card:C98,AFE_Card:C99 | 68pF | C_0805_2012Metric_Pad1.18x1.45mm_HandSolder
2 | 132203-12 | Amphenol RF | AFE_Card:J204,AFE_Card:J205 | LO1 ref SMA | SMA_Amphenol_132203-12_Horizontal
2 | FGA01FC | Thorlabs | AFE_Card:PD1,AFE_Card:PD2 | FGA01FC | PD_FGA01FC_EdgeBracket
1 | ERA-6AEB6041V | Panasonic | AFE_Card:R1 | 6.04k | R_0805_2012Metric_Pad1.20x1.40mm_HandSolder
2 | ERA-6AEB6651V | Panasonic | AFE_Card:R118,AFE_Card:R119 | 6.65k | R_0805_2012Metric_Pad1.20x1.40mm_HandSolder
2 | ERA-6AEB8251V | Panasonic | AFE_Card:R141,AFE_Card:R143 | 8.25k VB1 bot | R_0805_2012Metric_Pad1.20x1.40mm_HandSolder
1 | ERJ-6ENF3573V | Panasonic | AFE_Card:R144 | 357k PG top | R_0805_2012Metric_Pad1.20x1.40mm_HandSolder
2 | OPA814DBVR | Texas Instruments | AFE_Card:U30,AFE_Card:U31 | OPA814DBVR | OPA814DBVR
2 | AD835ARZ | Analog Devices | AFE_Card:U45,AFE_Card:U46 | AD835 demod | SOIC-8_3.9x4.9mm_P1.27mm
2 | OPA820IDBVR | Texas Instruments | AFE_Card:U204,AFE_Card:U205 | OPA820 LOx3 | SOT-23-5
1 | ESQ-107-12-G-D | Samtec | BTF_Card:J1 | ESQ-107-12-G-D | PinSocket_2x07_P2.54mm_Vertical
1 | 5253-100-7S | Azimuth Electronics | BTF_Card:JZ1 | Azimuth 5253-100-7S | Azimuth_5253-100-7S_ButterflyZIF
1 | 5253-100-7R | Azimuth Electronics | BTF_Card:JZ2 | Azimuth 5253-100-7R | Azimuth_5253-100-7R_ButterflyZIF
3 | CGA4J1X7R1H475K125AC | TDK | pm1p8V_pm5V_5Vref_5Vlaser:C25,pm1p8V_pm5V_5Vref_5Vlaser:C26,pm1p8V_pm5V_5Vref_5Vlaser:C54 | 4.7uF 50V X7R | C_0805_2012Metric_Pad1.18x1.45mm_HandSolder
3 | CL32B106KBJNNWE | Samsung Electro-Mechanics | pm1p8V_pm5V_5Vref_5Vlaser:C32,pm1p8V_pm5V_5Vref_5Vlaser:C33,pm1p8V_pm5V_5Vref_5Vlaser:C34 | 10uF 50V X7R | C_1210_3225Metric_Pad1.33x2.70mm_HandSolder
1 | C1206C106K3RACTU | KEMET | pm1p8V_pm5V_5Vref_5Vlaser:C13 | 10uF 25V X7R | C_1206_3216Metric_Pad1.33x1.80mm_HandSolder
4 | C1210C226M3RACTU | KEMET | pm1p8V_pm5V_5Vref_5Vlaser:C61,pm1p8V_pm5V_5Vref_5Vlaser:C62,pm1p8V_pm5V_5Vref_5Vlaser:C69,pm1p8V_pm5V_5Vref_5Vlaser:C71 | 22uF 25V X7R | C_1210_3225Metric_Pad1.33x2.70mm_HandSolder
1 | GRM2195C1H103JA01D | Murata Electronics | CH_Card:C70 | 10n C0G | C_0805_2012Metric_Pad1.18x1.45mm_HandSolder
1 | CL21C102JBCNFNC | Samsung Electro-Mechanics | CH_Card:C76 | Ci 1n C0G | C_0805_2012Metric_Pad1.18x1.45mm_HandSolder

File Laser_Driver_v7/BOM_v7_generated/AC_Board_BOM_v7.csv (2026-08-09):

Quantity | Manufacturer Part Number | Manufacturer | Customer Reference | Value | Footprint
3 | 1729131 | Phoenix Contact | J1,J2,J3 | Screw_Terminal_01x03 | TerminalBlock_Phoenix_MKDS-1,5-3-5.08_1x03_P5.08mm_Horizontal
1 | CRCW08051K00FKEA | Vishay Dale | R1 | 1k | R_0805_2012Metric_Pad1.20x1.40mm_HandSolder
1 | SL2210005 | Ametherm | TH1 | Ametherm SL22 10005 | R_Axial_DIN0411_L9.9mm_D3.6mm_P7.62mm_Vertical

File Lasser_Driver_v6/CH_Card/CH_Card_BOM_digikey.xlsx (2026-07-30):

Quantity | Manufacturer Part Number | Manufacturer | Customer Reference | Value | Footprint | Description
1 | AD5696RARUZ | Analog Devices Inc. | CH_Card U101 | AD5696R | TSSOP-16 | Quad 16-bit I2C DAC, int 2.5V ref, gain pin (setpoints; VDD=+5V, VLOGIC=3V3)
1 | ADS1115IDGSR | Texas Instruments | CH_Card U102 | ADS1115 | MSOP-10 | 16-bit 4ch sigma-delta I2C ADC (monitors)
1 | PCA9538PWR | Texas Instruments | CH_Card U103 | PCA9538 | TSSOP-16 | 8-bit I2C GPIO expander w/ INT (LOCK_EN, HB fault, FAULT_n)
4 | ADG419BRMZ | Analog Devices Inc. | CH_Card U26,U104,U105,U108 | ADG419BRM | MSOP-8 | SPDT analog switch (lock switch, ERR/MOD channel muxes, TEC 0 A safe-state)
5 | OPA192IDBVR | Texas Instruments | CH_Card U17,U19,U22,U24,U106 | OPA192 | SOT-23-5 | Precision op-amp 36V (VZERO buf, TEC err, laser set, summing, leg-1 drive inverter) - SEE NOTE: symbol unit renumber to DBV
2 | OPA551UA | Texas Instruments | CH_Card U21,U107 | OPA551U | SOIC-8 | Power op-amp 60V 200mA w/ thermal flag (H-bridge gate drivers: U21 = leg 2, U107 = leg 1)
2 | OPA380AIDR | Texas Instruments | CH_Card U_TIA1,U_TIA2 | OPA380 | SOIC-8 | 90MHz transimpedance amp (MPD monitor TIAs)
2 | INA828IDR | Texas Instruments | CH_Card U28,U32 | INA828 | SOIC-8 | Instrumentation amp SOIC-8 (laser/TEC current sense; INA826 successor, G=1+50k/RG - firmware cal absorbs +1.2%)
2 | IRL540NPBF | Infineon Technologies | CH_Card Q13,Q17 | IRL540N | TO-220-3 | N-MOSFET 100V logic-level (H-bridge high side; SUB for obsolete IRLB8721PBF)
2 | IRF9540NPBF | Infineon Technologies | CH_Card Q14,Q18 | IRF9540N | TO-220-3 | P-MOSFET -100V (H-bridge low side; same as pm6V)
1 | DMN3404L-7 | Diodes Incorporated | CH_Card Q19 | DMN3404L | SOT-23 | N-MOSFET 30V logic-level (laser current sink; SUB for IRLML6344 0-stock)
4 | MMSZ4702T1G | onsemi | CH_Card D16,D17,D20,D21 | 15V zener | SOD-123 | Zener 15V 500mW gate clamp - NOTE: change fp SOD-323 -> SOD-123
2 | BAT46W-TP | Micro Commercial Co | CH_Card D22,D23 | Schottky | SOD-123 | Schottky 100V 75mA - D22 laser reverse protect, D23 OPA551 flag clamp to 3V3
1 | CM453232-100KL | Bourns Inc. | CH_Card L1 | 10uH 1812 | L_1812 | Inductor 10uH 250mA 1.6R (laser bias tee; Isat > laser Imax 100mA)
2 | CRM2512-FX-R100ELF | Bourns Inc. | CH_Card R63,R65 | 0.1R 2W | R_2512 | Current sense 0.1R 1% 2W 2512 (TEC shunts; 2-terminal - Kelvin-route sense traces to pads at layout)
1 | WSL2512R2500FEA | Vishay Dale | CH_Card R81 | 0.25R 1W | R_2512 | Current sense 0.25R 1% 1W 2512 (laser shunt; 2-terminal - Kelvin-route at layout)
1 | RC2512FK-074R7L | YAGEO | CH_Card R86 | 4R7 1W | R_2512 | Res 4.7R 1% 1W (inrush limit)
4 | RC0805FR-07100RL | YAGEO | CH_Card R111,R112,R113,R114 | 100R | R_0805 | Res 100R 1% (I2C series, DAC filters)
17 | RC0805FR-0710KL | YAGEO | CH_Card R79,R92,R115,R120,R121,R122,R123,R124,R125,R127,R128,R129,R130,R131,R133,R_f1,R_f2 | 10k | R_0805 | Res 10k 1% (pullups/pulldowns/sum/filters)
4 | RC0805FR-0710RL | YAGEO | CH_Card R48,R116,R126,R132 | 10R | R_0805 | Res 10R 1% (gate stop, rail filters)
3 | RC0805FR-0747RL | YAGEO | CH_Card R69,R70,R75 | 47R | R_0805 | Res 47R 1% (NTC + monitor line protection; gate drive moved to the 470R line)
3 | CRCW08051K00FKEA | Vishay Dale | CH_Card R42,R55,R94 | 1k | R_0805 | Res 1k 1% (divider, flag, parallel)
1 | RC0805FR-073K16L | YAGEO | CH_Card R41 | 3.16k | R_0805 | Res 3.16k 1% (VZERO divider top)
1 | RC0805FR-078K06L | YAGEO | CH_Card R102 | 8.06k | R_0805 | Res 8.06k 1% (INA826 gain, TEC)
1 | RC0805FR-07487RL | YAGEO | CH_Card R98 | 487R | R_0805 | Res 487R 1% (INA826 gain, laser)
2 | RC0805FR-072KL | YAGEO | CH_Card R77,R117 | 2k | R_0805 | Res 2k 1% (R77 RF trim; R117 VZERO trim series - was 4.99k, in series with R43 20k into VZERO_SET so it sets the DAC trim span)
1 | ERA-6AEB103V | Panasonic Industry | CH_Card R_NTC1 | 10k 0.1% | R_0805 | Res 10k 0.1% (NTC pullup; same as pm1p8V)
3 | ERA-6AEB203V | Panasonic Industry | CH_Card R43,R45,R_bias1 | 20k 0.1% | R_0805 | Res 20k 0.1% (TEC scaler bottom R43/R45; PD monitor bias R_bias1)
1 | ERA-6AEB204V | Panasonic Industry | CH_Card R66 | 200k 0.1% | R_0805 | Res 200k 0.1% (laser scaler top)
3 | TNPW08054K99BEEA | Vishay Dale | CH_Card R44,R118,R119 | 4.99k 0.1% | R_0805 | Res 4.99k 0.1% (TEC scaler top, ADC prot) - ERA-6AEB4991V 0 stock
45 | CL21B104KBCNNNC | Samsung Electro-Mechanics | CH_Card C65,C66,C116,C117,C118,C122,C123,C130,C131,C132,C133,C134,C135,C136,C137,C138,C139,C140,C141,C142,C143,C144,C145,C146,C147,C148,C149,C152,C153,C155,C156,C158,C161,C164,C165,C166,C167,C168,C169,C170,C171,C172,C173,C174,C_NTC1 | 100nF | C_0805 | MLCC 100nF 50V X7R (decoupling bank + misc; same as pm1p8V)
2 | C0805C105K5RACTU | KEMET | CH_Card C113,C114 | 1uF | C_0805 | MLCC 1uF 50V X7R (DAC output filters; same as pm1p8V)
8 | C0805C106K3PACTU | KEMET | CH_Card C115,C121,C150,C151,C154,C157,C160,C163 | 10uF | C_0805 | MLCC 10uF 25V X5R (rail bulk; same as pm1p8V)
2 | 1210YD107MAT2A | KYOCERA AVX | CH_Card C159,C162 | 100uF | C_1210 | MLCC 100uF 16V X5R (+/-6V_TEC bulk; same as pm1p8V)
2 | CL21B103KBANNNC | Samsung Electro-Mechanics | CH_Card C119,C120 | 10nF | C_0805 | MLCC 10nF 50V X7R (ADC input filters)
1 | C0805C103J5GACTU | KEMET | CH_Card C70 | 10nF C0G | C_0805 | MLCC 10nF 50V C0G (laser filter)
1 | CL21B102KBANNNC | Samsung Electro-Mechanics | CH_Card C76 | 1nF | C_0805 | MLCC 1nF 50V X7R (lock integrator Ci)
1 | CL21C101JBANNNC | Samsung Electro-Mechanics | CH_Card C68 | 100pF NP0 | C_0805 | MLCC 100pF 50V C0G (comp)
2 | GRM1555C1H2R2CA01D | Murata Electronics | CH_Card C_f1,C_f2 | 2.2pF | C_0402 | MLCC 2.2pF 50V C0G 0402 (TIA feedback; CL05C2R2CB5NNNC obsolete)
1 | 374144-E | TE Connectivity AMP | CH_Card J1 | DIN41612 M 3x8+8 | DIN41612_M_Power_Male | DIN41612 Type M 24sig+8pwr R/A male (same as pm6V/pm1p8V) - 0 STOCK, check lead time
1 | 61301421121 | Würth Elektronik | CH_Card J_BTF1 | 2x7 pin header | PinHeader_2x07_P2.54mm_Vertical | Würth WR-PHD 2.54mm 2x7 male pin header - board side of the off-board laser-head harness; same connector family as the LDM-BUTTERFLY mount socket (Würth 61301421821). Wire assembly (cable) sourced separately - spec 24AWG for the TEC pair.
3 | 61300211121 | Wurth Elektronik | CH_Card JP101,JP102,JP103 | 1x2 header | PinHeader_1x02 | Pin header 1x2 2.54mm (GA address jumpers)
3 | SPC02SYAN | Sullins Connector | CH_Card JP101-103 shunts | shunt | - | Shorting jumper 2.54mm gold (fit = address bit 0)
4 | 657-10ABPE | Wakefield Thermal Solutions | CH_Card HS1,HS2,HS3,HS4 | Heatsink TO-220 vert 1in | TO-220-3_Vertical_HS657 | Vert board-mount heatsink 657-series 25.4mm, 6.8C/W nat (TEC H-bridge Q13/Q14/Q17/Q18; same as pm6V)
4 | 4880G | Boyd | CH_Card Q13,Q14,Q17,Q18 (TO-220 iso) | TO-220 mount kit | Hardware (off-PCB) | Insulator+shoulder washer kit; isolates FET tab from heatsink (tabs are live: +6V_TEC / bridge outputs)
4 | PMSSS 440 0050 PH | B&F Fastener Supply | CH_Card Q13-Q18 heatsink mount | #4-40 x 1/2in screw | Hardware (off-PCB) | SS pan-head machine screw #4-40 x 1/2in (FET to 657 web)
4 | FWSS 004 | B&F Fastener Supply | CH_Card Q13-Q18 heatsink mount | #4 flat washer | Hardware (off-PCB) | SS #4 flat washer, nut side
4 | INTLWZ 004 | B&F Fastener Supply | CH_Card Q13-Q18 heatsink mount | #4 int-tooth lock washer | Hardware (off-PCB) | Internal-tooth lock washer #4 (anti-rotation)
4 | HNZ 440 | B&F Fastener Supply | CH_Card Q13-Q18 heatsink mount | #4-40 hex nut | Hardware (off-PCB) | #4-40 hex nut, zinc-plated steel
2 | WSL2512R0100FEA | Vishay Dale | CH_Card R68,R76 | 10mR link | R_2512 | 0.01R 1% 1W 2512 - TEC drive links to butterfly (was 47R: blocked TEC current)
2 | RC0805JR-070RL | YAGEO | CH_Card R73,R74 | 0R link | R_0805 | 0R jumper - laser CHIP+/- links (was 47R: no laser headroom)
1 | ERA-6AEB9090V | Panasonic Industry | CH_Card R67 | 909R 0.1% | R_0805 | Res 909R 0.1% (laser scaler BOTTOM, to GND) - sets DAC full scale 90.5 mA
1 | RC0805FR-077M5L | YAGEO | CH_Card R96 | 7.5M | R_0805 | Res 7.5M 1% (PDH servo injection into the laser setpoint; 0.483 mA/V)
1 | RC0805JR-0715ML | YAGEO | CH_Card R134 | 15M | R_0805 | Res 15M 5% (cancels U24's 2.500V VREF_MID pedestal via -5V; exact 2:1 with R96)
1 | RC0805FR-0733KL | YAGEO | CH_Card R49 | 33k | R_0805 | Res 33k 1% (OPA551 flag PULL-DOWN: flag is a current source, 80uA min -> 2.64V > VIH)
4 | RC0805FR-07470RL | YAGEO | CH_Card R56,R57,R58,R59 | 470R | R_0805 | Res 470R 1% gate drive - 47R let a saturated buffer pull 353 mA from a 200 mA OPA551
1 | RC0805FR-07100KL | YAGEO | CH_Card R78 | 100k | R_0805 | Res 100k 1% - DC bleed on the MOD injection island (C66-R77-C70); was missing from the BOM

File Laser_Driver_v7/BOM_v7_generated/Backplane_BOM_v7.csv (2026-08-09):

Quantity | Manufacturer Part Number | Manufacturer | Customer Reference | Value | Footprint
1 | CL21B104KBCNNNC | Samsung Electro-Mechanics | C1 | 100n | C_0805_2012Metric_Pad1.18x1.45mm_HandSolder
1 | SMAJ5.0CA-E3/61 |  | D3 | SMAJ5.0CA | D_SMA-SMB_Universal_Handsoldering
8 | 09032966855 | HARTING | J1,J2,J3,J4,J5,J6,J7,J8 | DIN41612_03x32_C_Split | DIN41612_C_3x32_Female_Vertical_THT
1 | RC0805JR-070RL | YAGEO | R1 | 0 | R_0805_2012Metric_Pad1.20x1.40mm_HandSolder

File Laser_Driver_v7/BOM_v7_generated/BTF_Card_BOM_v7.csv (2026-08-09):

Quantity | Manufacturer Part Number | Manufacturer | Customer Reference | Value | Footprint
1 | ESQ-107-12-G-D | Samtec | J1 | ESQ-107-12-G-D | PinSocket_2x07_P2.54mm_Vertical
1 | 61300211121 | Wurth Elektronik | JP1 | LD SHORT | PinHeader_1x02_P2.54mm_Vertical
1 | 5253-100-7S | Azimuth Electronics | JZ1 | Azimuth 5253-100-7S | Azimuth_5253-100-7S_ButterflyZIF
1 | 5253-100-7R | Azimuth Electronics | JZ2 | Azimuth 5253-100-7R | Azimuth_5253-100-7R_ButterflyZIF

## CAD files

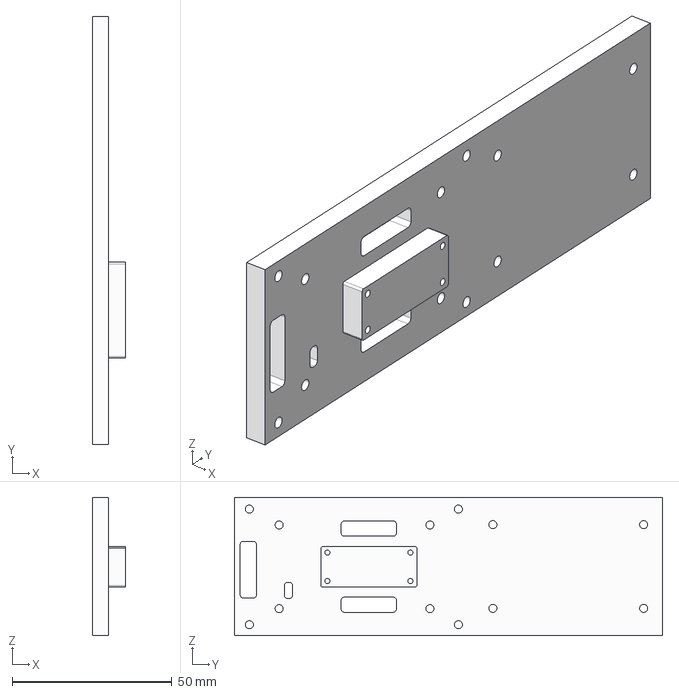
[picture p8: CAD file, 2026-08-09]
3d_model/BTF_heatsink.step
10.2 x 134.0 x 43.4 mm

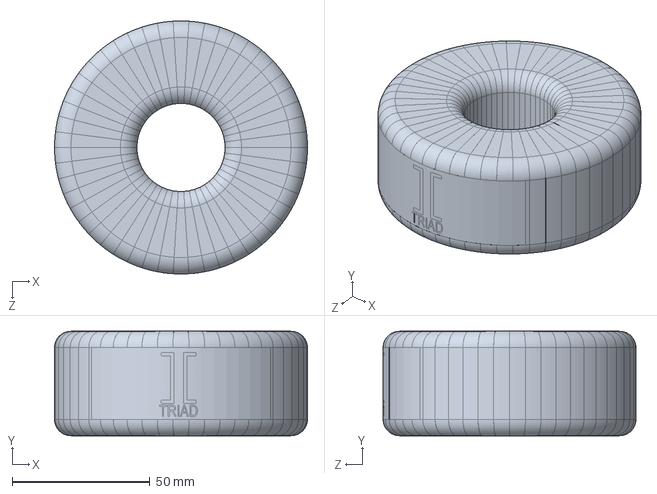
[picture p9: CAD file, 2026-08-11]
3d_model/VPM30-1670--3DModel-STEP-884787/VPM30-1670--3DModel-STEP-884787.STEP
92.0 x 38.0 x 92.0 mm

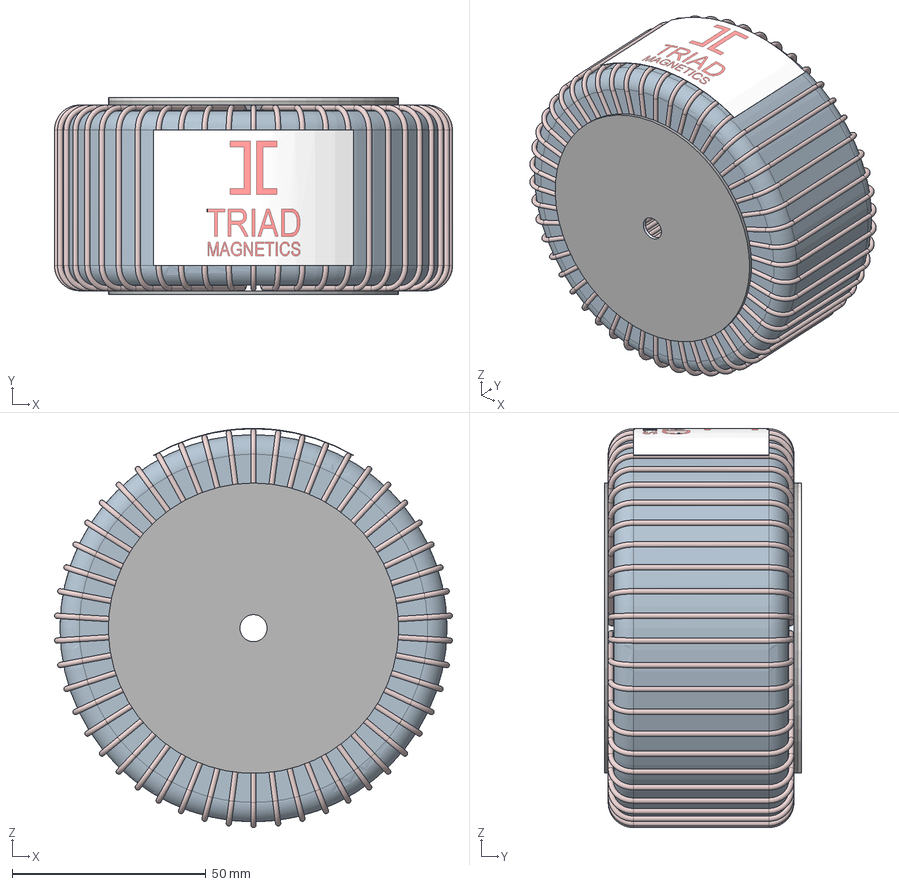
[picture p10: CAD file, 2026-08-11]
3d_model/VPT18-8800--3DModel-STEP-884787/VPT18-8800--3DModel-STEP-884787.STEP
102.8 x 51.0 x 103.1 mm

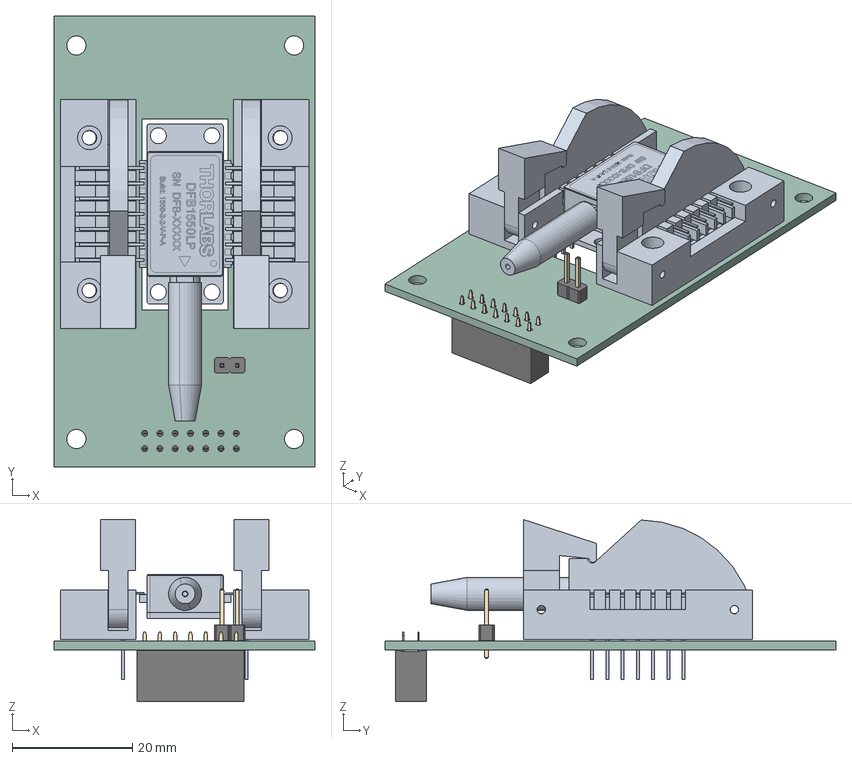
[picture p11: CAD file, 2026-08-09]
Laser_Driver_v7/3d/BTF_Card.step
43.4 x 75.0 x 30.3 mm
PinHeader_1x02_P254mm_Vertical
PinSocket_2x07_P2.54mm_Vertical
BTF_Card_PCB

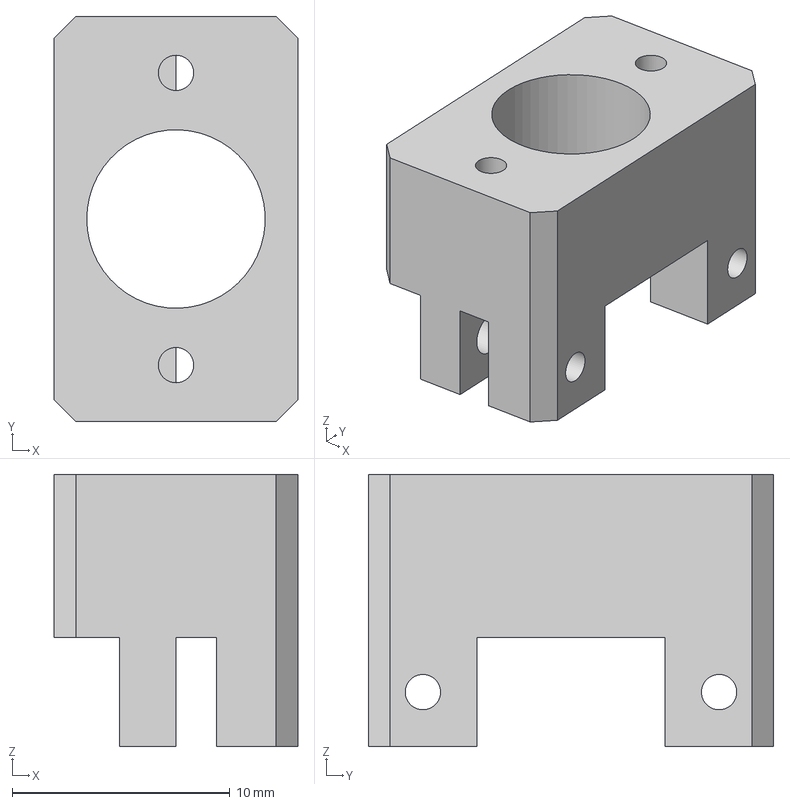
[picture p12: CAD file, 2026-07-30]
Photodiode/Bracket v5.step
11.2 x 18.6 x 12.5 mm

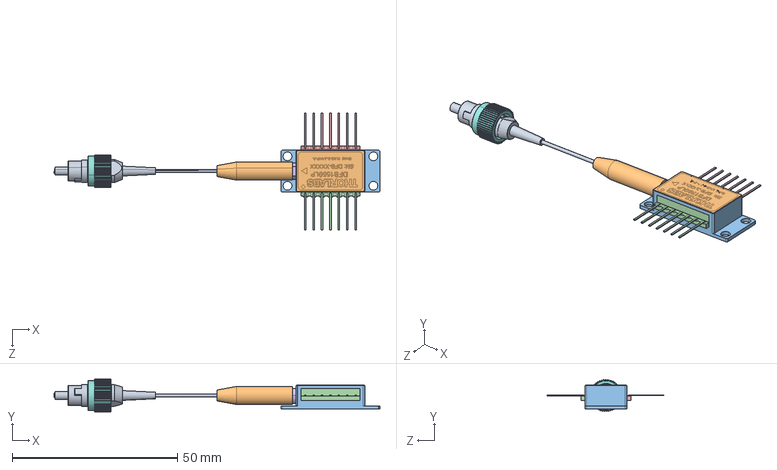
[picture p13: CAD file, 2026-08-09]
SpecSheets/DFB Butterfly packages/DFB1550LP-Step.step
98.7 x 9.86 x 35.5 mm

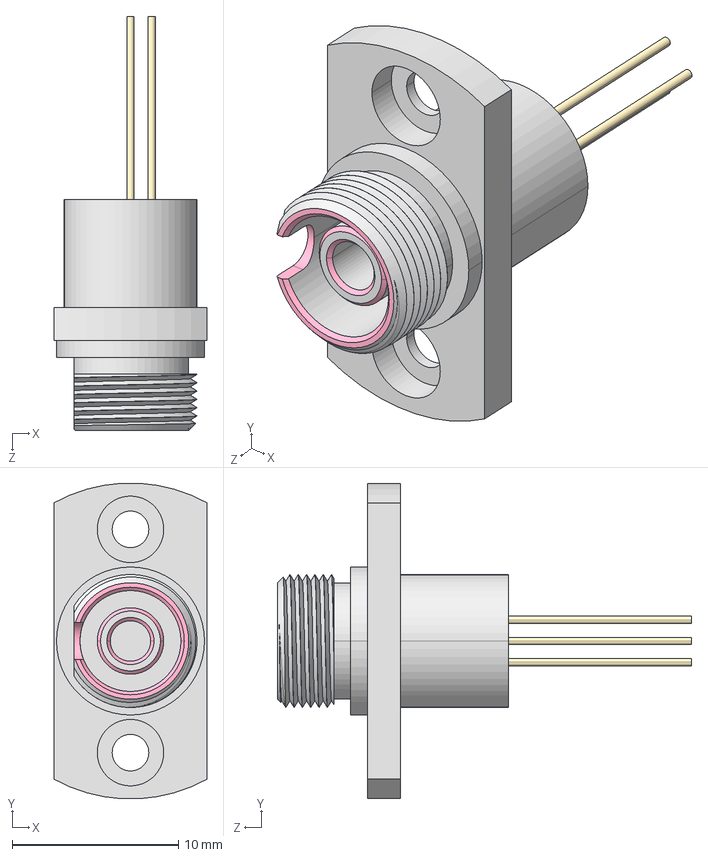
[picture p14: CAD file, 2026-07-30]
SpecSheets/FGA01FC-Step.step
9.20 x 19.0 x 24.9 mm

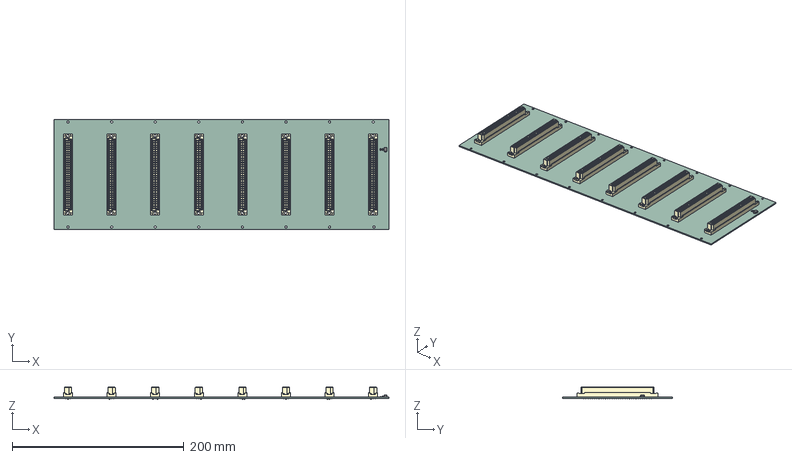
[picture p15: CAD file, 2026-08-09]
Laser_Driver_v7/3d/Backplane_Slots.step
390.4 x 128.6 x 14.1 mm
D_SMB
R_0805_2012Metric
C_0805_2012Metric
Backplane_Slots_PCB

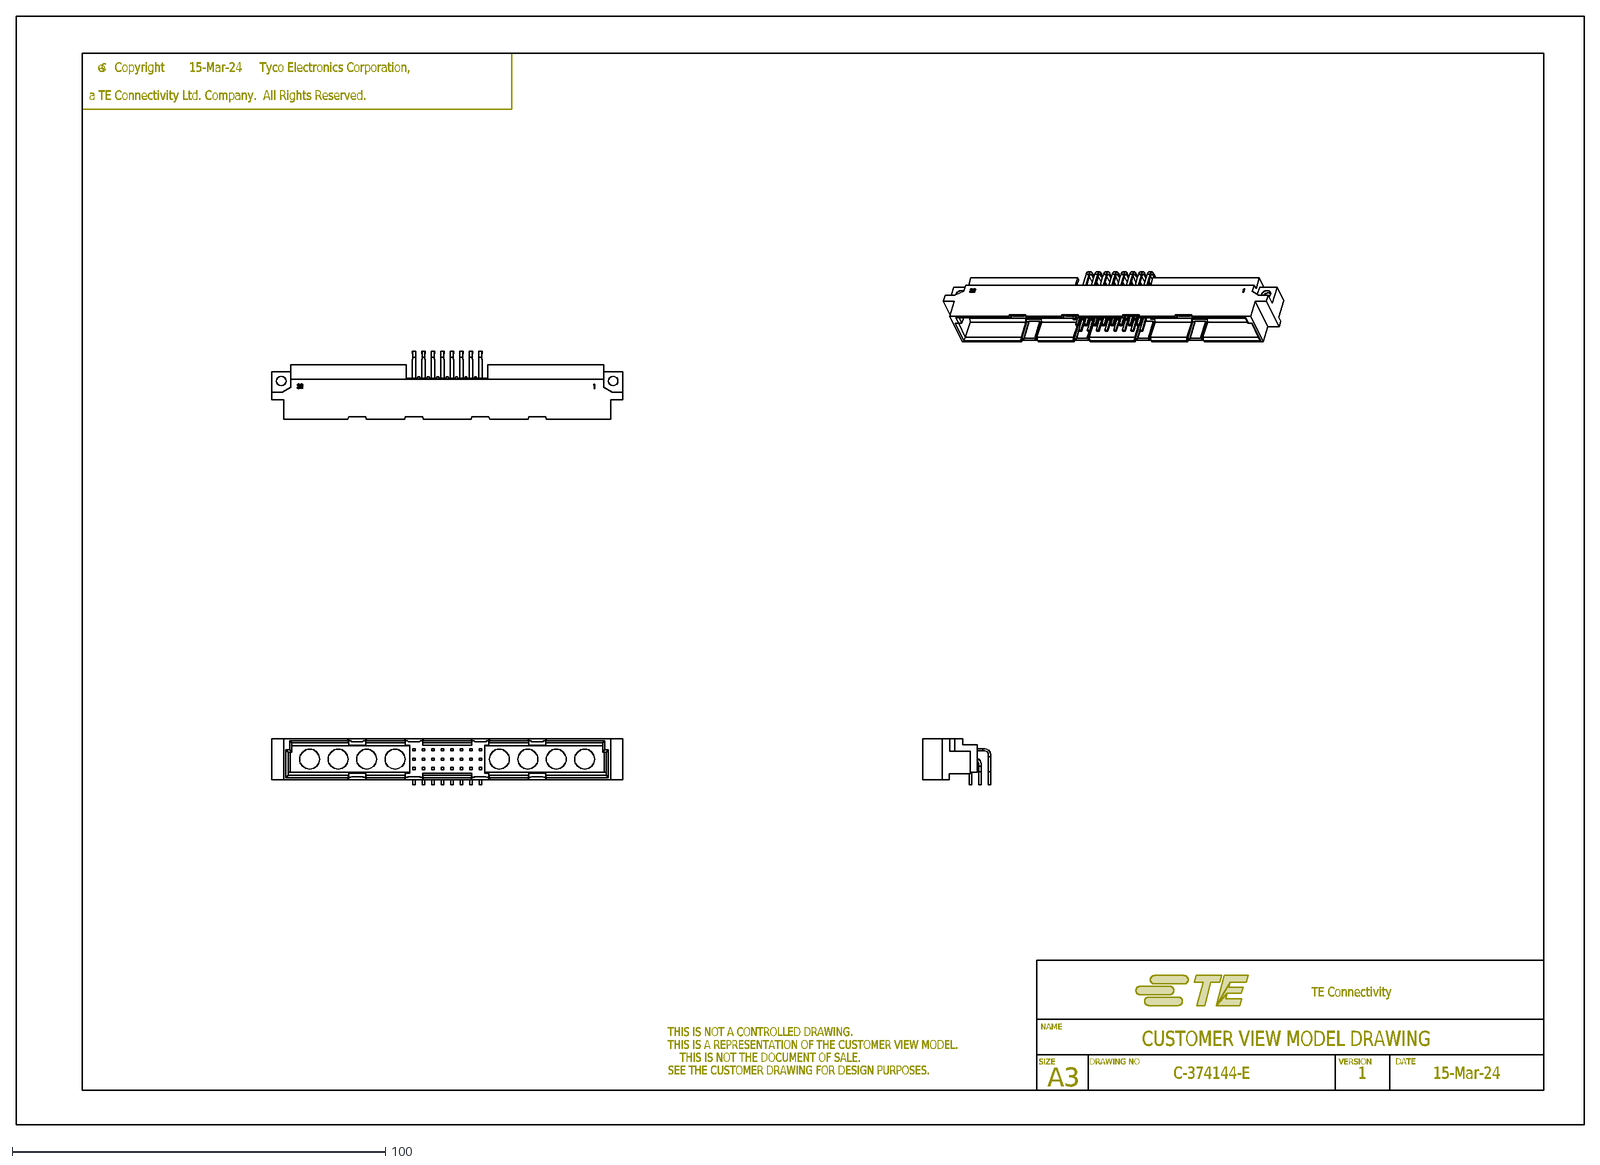
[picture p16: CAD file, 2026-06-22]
SpecSheets/c-374144-e-1-2d.dxf
SIZE
DRAWING NO
VERSION
NAME
A3
CUSTOMER VIEW MODEL DRAWING
TE Connectivity
DATE
THIS IS NOT A CONTROLLED DRAWING.
THIS IS A REPRESENTATION OF THE CUSTOMER VIEW MODEL.
THIS IS NOT THE DOCUMENT OF SALE.
SEE THE CUSTOMER DRAWING FOR DESIGN PURPOSES.
c
C-374144-E
1
15-Mar-24
Copyright
Tyco Electronics Corporation,
a TE Connectivity Ltd. Company. All Rights Reserved.

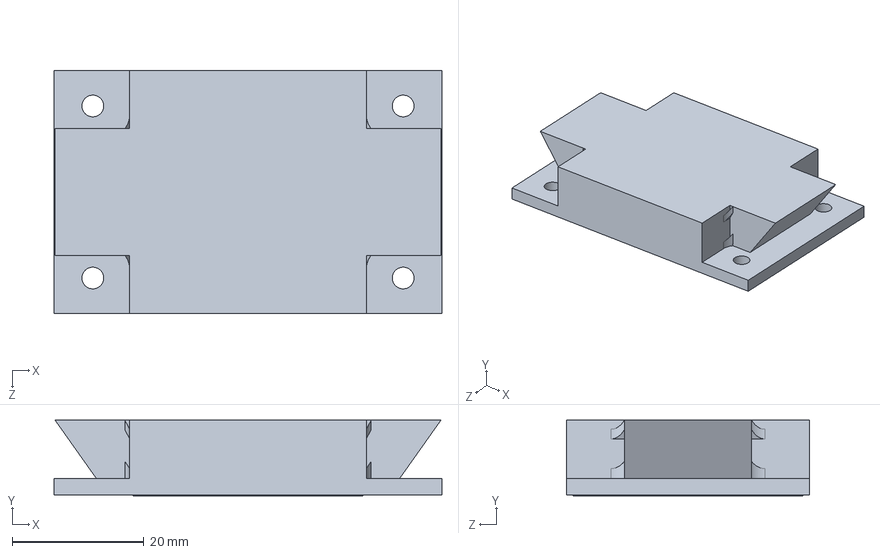
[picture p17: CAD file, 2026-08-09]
3d_model/ATS-1139_FUSED.STEP
59.0 x 11.6 x 37.0 mm

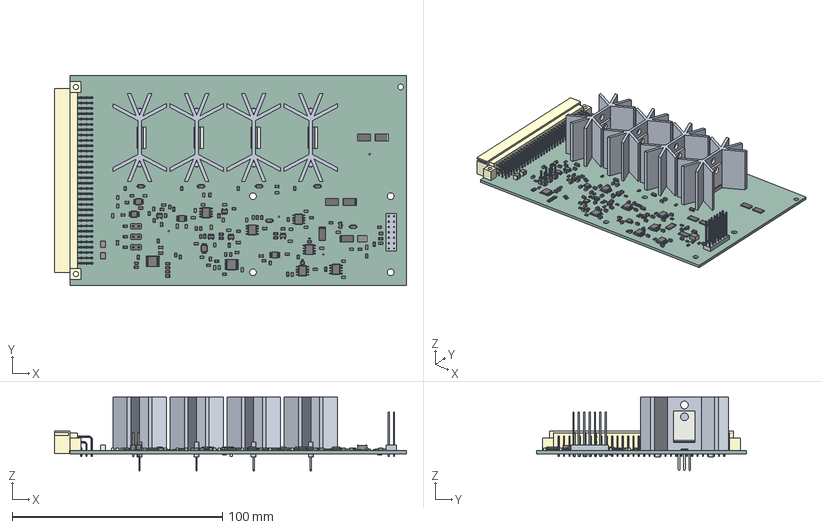
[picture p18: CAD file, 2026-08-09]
Laser_Driver_v7/3d/CH_Card.step
167.4 x 100.0 x 35.1 mm
C_0805_2012Metric x 61
SOIC-8_3.9x4.9mm_P1.27mm x 6
R_0805_2012Metric x 55
TSSOP-16_4.4x5mm_P0.65mm x 2
TO-220-3_Vertical x 4
R_2512_6332Metric x 6
L_1812_4532Metric
D_SOD-123 x 6
SOT-23-5 x 5
MSOP-8_3x3mm_P0.65mm x 4
C_0402_1005Metric x 2
PinHeader_1x02_P254mm_Vertical x 3
MSOP-10_3x3mm_P0.5mm
SOT-23
DIN41612_C_3xN_Male_Horizontal_THT
C_1210_3225Metric x 2
CH_Card_PCB

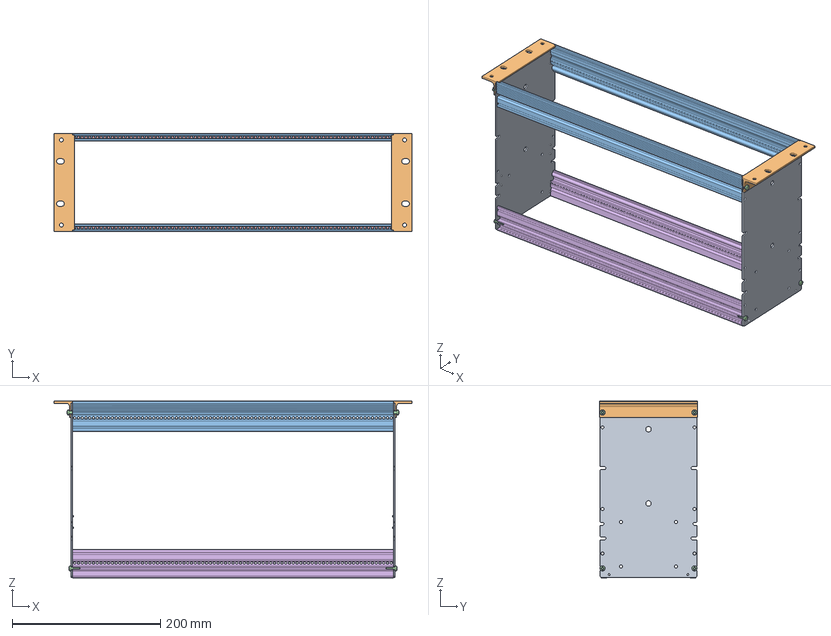
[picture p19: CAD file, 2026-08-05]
3d_model/CADesigns_3634110_subrack.stp
482.4 x 132.0 x 238.0 mm
P02370XXRVXX_235 x 2
P02378XXRVXX_003 x 2
P02367RVXX_084 x 2
P02514XXRVXX-SYM x 8
J31813-1214-Y084 x 2
P02363XXRVXX_084 x 2

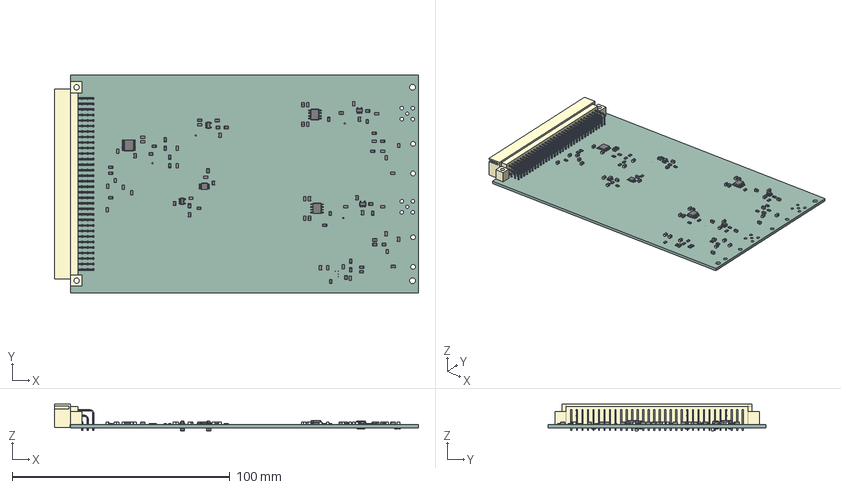
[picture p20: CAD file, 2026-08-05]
Laser_Driver_v7/3d/AFE_Card.step
167.3 x 100.0 x 12.3 mm
C_0805_2012Metric x 51
SOT-23-5 x 4
R_0805_2012Metric x 39
SOIC-8_3.9x4.9mm_P1.27mm x 2
TSSOP-16_4.4x5mm_P0.65mm
DIN41612_C_3xN_Male_Horizontal_THT
MSOP-10_3x3mm_P0.5mm
C_0402_1005Metric x 2
AFE_Card_PCB

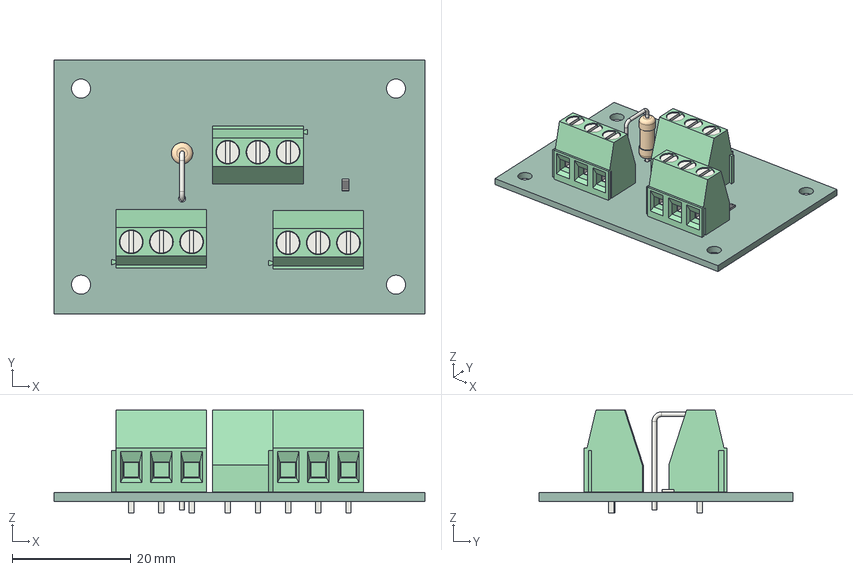
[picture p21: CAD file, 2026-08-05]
Laser_Driver_v7/3d/AC_Board.step
62.4 x 42.7 x 17.3 mm
R_Axial_DIN0411_L99mm_D36mm_P762mm_Vertical
R_0805_2012Metric
TerminalBlock_Phoenix_MKDS-1,5-3-5.08_1x03_P5.08mm_Horizontal x 3
AC_Board_PCB

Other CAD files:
Photodiode/DFB1550L-Step.step
Laser_Driver_v7/3d/pm6V.step
Laser_Driver_v7/3d/pm22V.step
Laser_Driver_v7/3d/DIG_Card.step
3d_model/95947A500_Lightweight Aluminum Female Threaded Hex Standoff.STEP
3d_model/BTF_heatsink.f3d
Laser_Driver_v7/3d/pm1p8V_pm5V_5Vref_5Vlaser.step
Photodiode/Bracket v5.f3d

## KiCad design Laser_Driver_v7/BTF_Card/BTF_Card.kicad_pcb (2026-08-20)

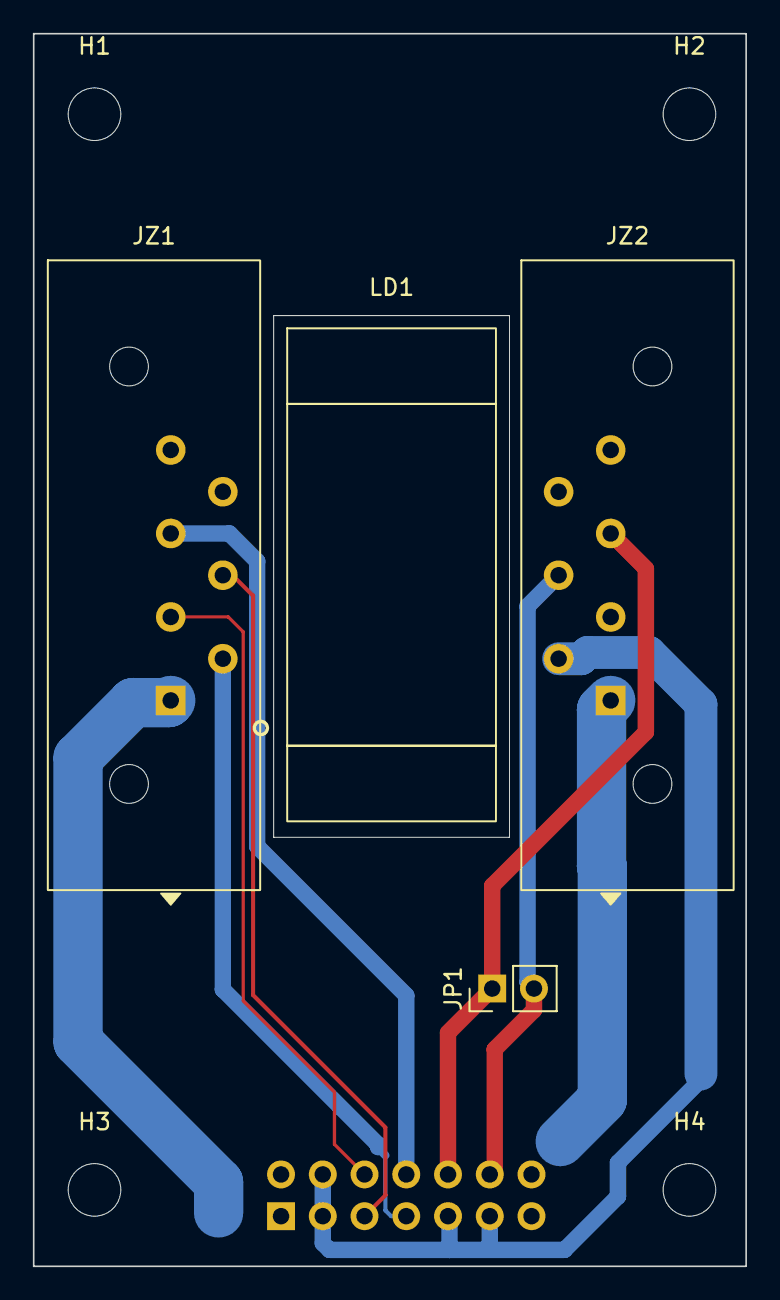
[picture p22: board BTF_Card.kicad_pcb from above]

Board: 2 copper layers, 43.4 x 75.0 mm, 9 parts (1 on the bottom side), 9 nets.

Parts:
H1, H2, H3, H4: M3; MountingHole_3.2mm_M3
J1: ESQ-107-12-G-D; PinSocket_2x07_P2.54mm_Vertical
JP1: LD SHORT; PinHeader_1x02_P2.54mm_Vertical
JZ1: Azimuth 5253-100-7S; Azimuth_5253-100-7S_ButterflyZIF
JZ2: Azimuth 5253-100-7R; Azimuth_5253-100-7R_ButterflyZIF
LD1: DFB1550LP; DFB1550LP_Butterfly14_Mech

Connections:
CASE: J1.3, J1.4, J1.9, J1.11, JZ2.2
LD_A: J1.10, JP1.1 (A), JZ2.5
LD_K: J1.12, JP1.2 (B), JZ2.4
MPD_A: J1.6, JZ1.3
MPD_K: J1.5, JZ1.4
NTC_A: J1.7, JZ1.2
NTC_GND: J1.8, JZ1.5
TEC_N: J1.13, J1.14, JZ2.1
TEC_P: J1.1, J1.2, JZ1.1

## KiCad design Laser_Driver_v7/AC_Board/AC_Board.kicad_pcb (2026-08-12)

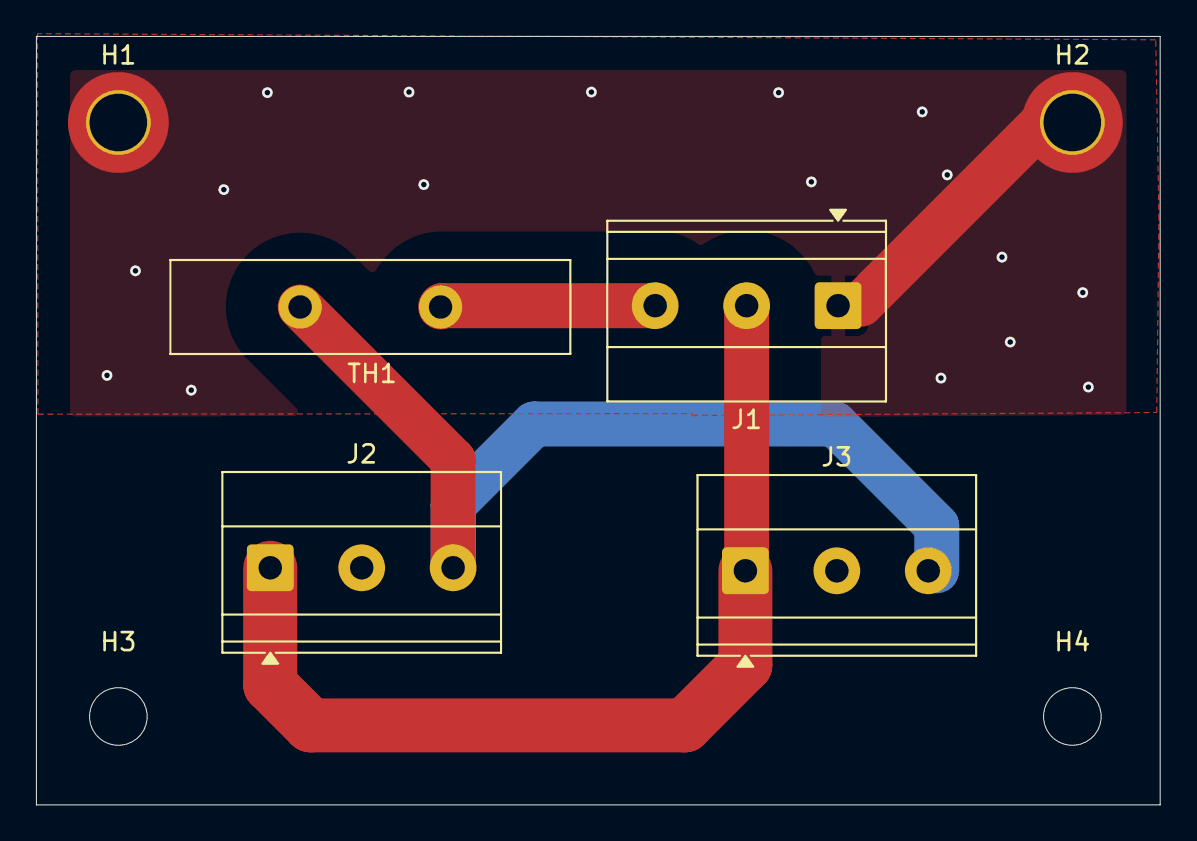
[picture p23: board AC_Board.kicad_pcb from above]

Board: 2 copper layers, 62.4 x 42.7 mm, 8 parts (0 on the bottom side), 4 nets.

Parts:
H1, H2: MountingHole_Pad; MountingHole_3.2mm_M3_DIN965_Pad_TopBottom
H3, H4: MountingHole; MountingHole_3.2mm_M3
J1, J2, J3: Screw_Terminal_01x03; TerminalBlock_Phoenix_MKDS-1,5-3-5.08_1x03_P5.08mm_Horizont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
TH1: Ametherm SL22 10005; Thermistor_Disc_D22.0mm_W5.0mm_P7.80mm_Ametherm_SL22

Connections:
120Vac: J1.3, TH1.1
/Line_TH: J2.3, J3.3, TH1.2
Earth: H1.1 (1_1), H2.1 (1_1), J1.1
Neutral: J1.2, J2.1, J3.1

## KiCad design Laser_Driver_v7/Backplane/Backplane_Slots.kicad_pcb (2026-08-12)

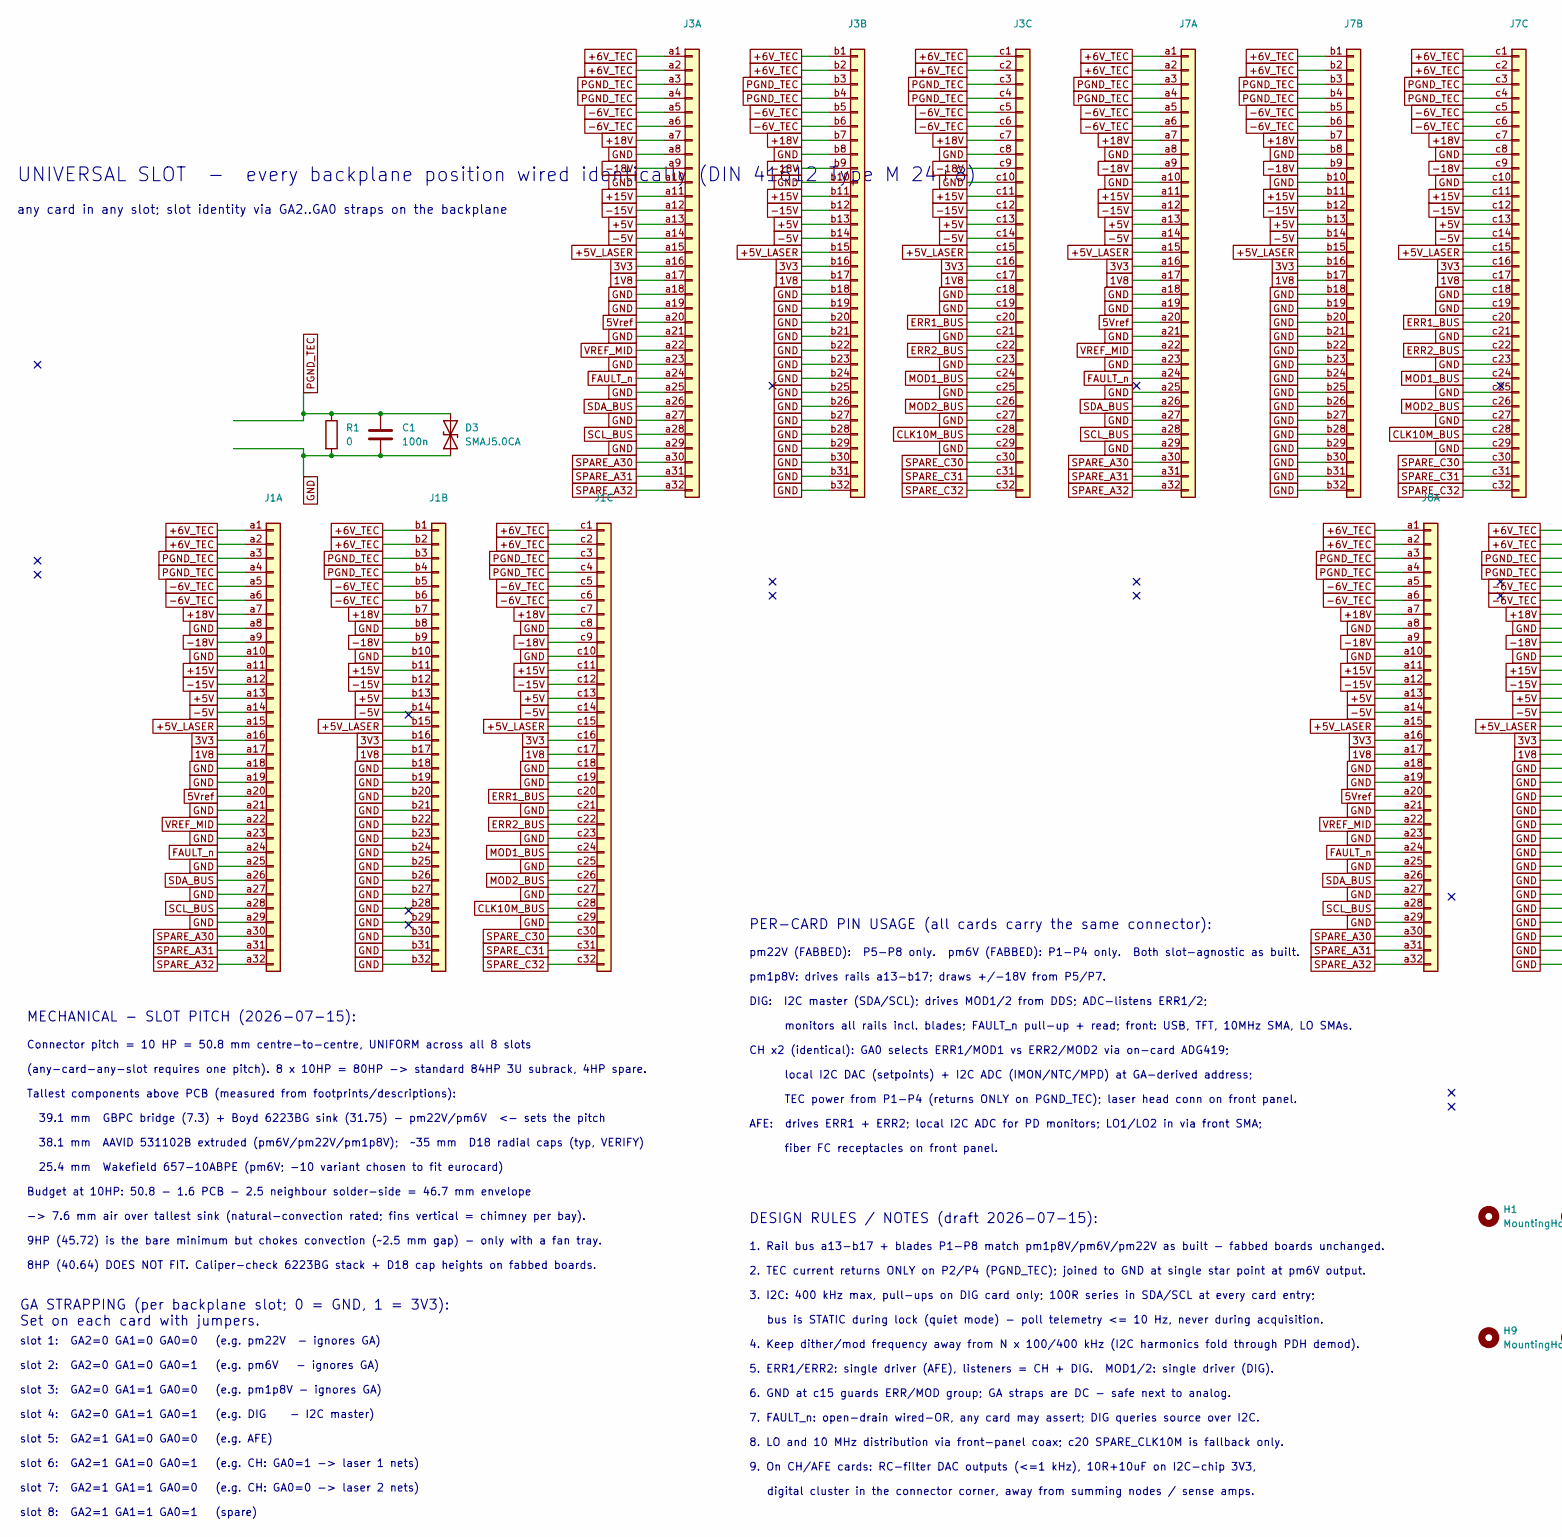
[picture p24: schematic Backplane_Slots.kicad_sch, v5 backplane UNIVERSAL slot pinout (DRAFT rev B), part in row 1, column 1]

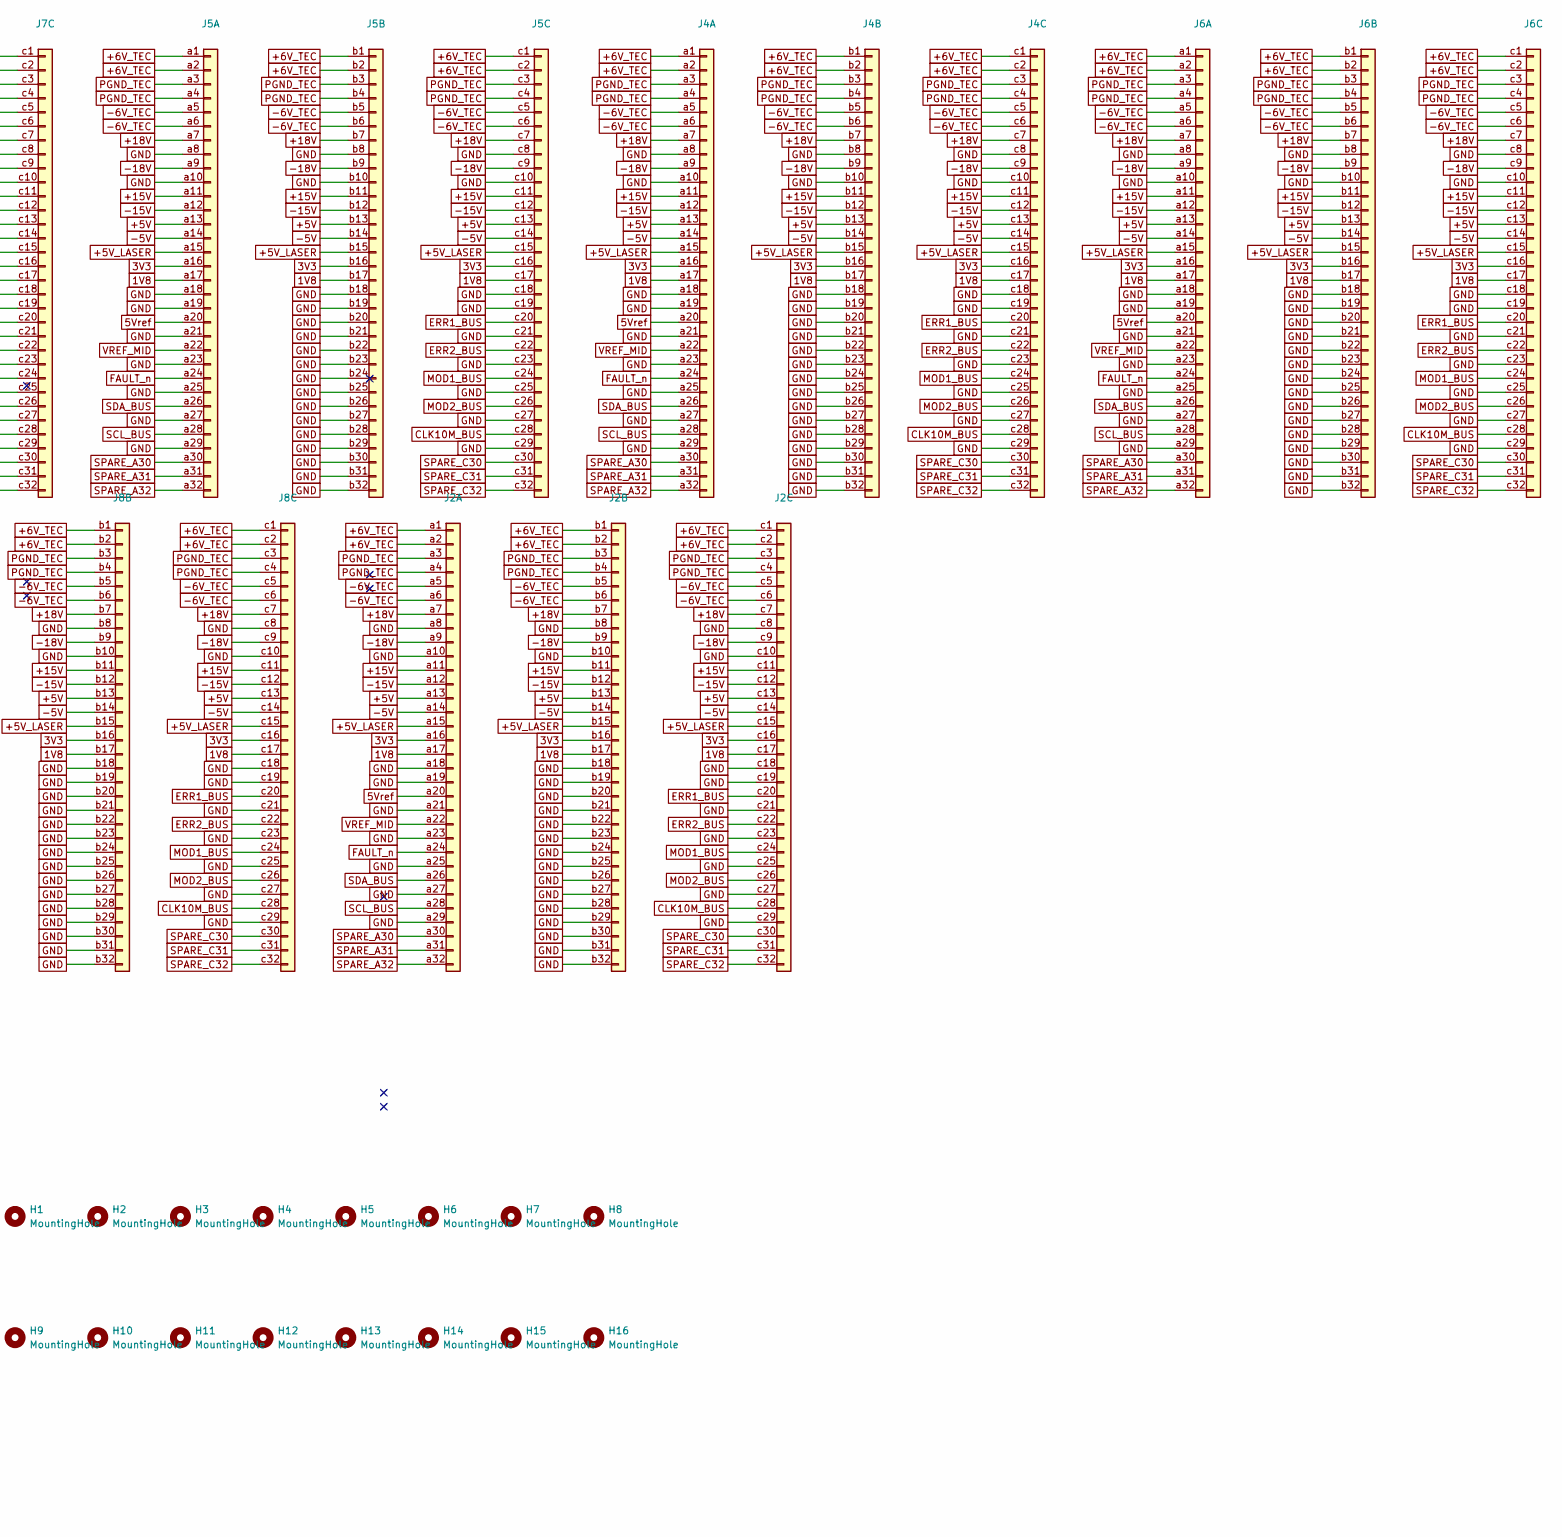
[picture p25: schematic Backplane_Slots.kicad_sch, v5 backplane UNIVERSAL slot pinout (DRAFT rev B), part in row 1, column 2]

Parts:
C1: 100n; C_0805_2012Metric_Pad1.18x1.45mm_HandSolder
D3: SMAJ5.0CA; D_SMA-SMB_Universal_Handsoldering; MPN SMAJ5.0CA-E3/61
H1, H2, H3, H4, H5, H6, H7, H8, H9, H10, H11, H12, H13, H14, H15, H16: MountingHole; MountingHole_2.7mm
J1, J2, J3, J4, J5, J6, J7, J8: DIN41612_03x32_C_Split; DIN41612_C_3x32_Female_Vertical_THT
R1: 0; R_0805_2012Metric_Pad1.20x1.40mm_HandSolder

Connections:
1V8: J1.a17, J1.b17, J1.c17, J2.a17, J2.b17, J2.c17, J3.a17, J3.b17, J3.c17, J4.a17, J4.b17, J4.c17, J5.a17, J5.b17, J5.c17, J6.a17, J6.b17, J6.c17, J7.a17, J7.b17, J7.c17, J8.a17, J8.b17, J8.c17
3V3: J1.a16, J1.b16, J1.c16, J2.a16, J2.b16, J2.c16, J3.a16, J3.b16, J3.c16, J4.a16, J4.b16, J4.c16, J5.a16, J5.b16, J5.c16, J6.a16, J6.b16, J6.c16, J7.a16, J7.b16, J7.c16, J8.a16, J8.b16, J8.c16
5Vref: J1.a20, J2.a20, J3.a20, J4.a20, J5.a20, J6.a20, J7.a20, J8.a20
+5V: J1.a13, J1.b13, J1.c13, J2.a13, J2.b13, J2.c13, J3.a13, J3.b13, J3.c13, J4.a13, J4.b13, J4.c13, J5.a13, J5.b13, J5.c13, J6.a13, J6.b13, J6.c13, J7.a13, J7.b13, J7.c13, J8.a13, J8.b13, J8.c13
+5V_LASER: J1.a15, J1.b15, J1.c15, J2.a15, J2.b15, J2.c15, J3.a15, J3.b15, J3.c15, J4.a15, J4.b15, J4.c15, J5.a15, J5.b15, J5.c15, J6.a15, J6.b15, J6.c15, J7.a15, J7.b15, J7.c15, J8.a15, J8.b15, J8.c15
+6V_TEC: J1.a1, J1.a2, J1.b1, J1.b2, J1.c1, J1.c2, J2.a1, J2.a2, J2.b1, J2.b2, J2.c1, J2.c2, J3.a1, J3.a2, J3.b1, J3.b2, J3.c1, J3.c2, J4.a1, J4.a2, J4.b1, J4.b2, J4.c1, J4.c2, J5.a1, J5.a2, J5.b1, J5.b2, J5.c1, J5.c2, J6.a1, J6.a2, J6.b1, J6.b2, J6.c1, J6.c2, J7.a1, J7.a2, J7.b1, J7.b2, J7.c1, J7.c2, J8.a1, J8.a2, J8.b1, J8.b2, J8.c1, J8.c2
+15V: J1.a11, J1.b11, J1.c11, J2.a11, J2.b11, J2.c11, J3.a11, J3.b11, J3.c11, J4.a11, J4.b11, J4.c11, J5.a11, J5.b11, J5.c11, J6.a11, J6.b11, J6.c11, J7.a11, J7.b11, J7.c11, J8.a11, J8.b11, J8.c11
+18V: J1.a7, J1.b7, J1.c7, J2.a7, J2.b7, J2.c7, J3.a7, J3.b7, J3.c7, J4.a7, J4.b7, J4.c7, J5.a7, J5.b7, J5.c7, J6.a7, J6.b7, J6.c7, J7.a7, J7.b7, J7.c7, J8.a7, J8.b7, J8.c7
-5V: J1.a14, J1.b14, J1.c14, J2.a14, J2.b14, J2.c14, J3.a14, J3.b14, J3.c14, J4.a14, J4.b14, J4.c14, J5.a14, J5.b14, J5.c14, J6.a14, J6.b14, J6.c14, J7.a14, J7.b14, J7.c14, J8.a14, J8.b14, J8.c14
-6V_TEC: J1.a5, J1.a6, J1.b5, J1.b6, J1.c5, J1.c6, J2.a5, J2.a6, J2.b5, J2.b6, J2.c5, J2.c6, J3.a5, J3.a6, J3.b5, J3.b6, J3.c5, J3.c6, J4.a5, J4.a6, J4.b5, J4.b6, J4.c5, J4.c6, J5.a5, J5.a6, J5.b5, J5.b6, J5.c5, J5.c6, J6.a5, J6.a6, J6.b5, J6.b6, J6.c5, J6.c6, J7.a5, J7.a6, J7.b5, J7.b6, J7.c5, J7.c6, J8.a5, J8.a6, J8.b5, J8.b6, J8.c5, J8.c6
-15V: J1.a12, J1.b12, J1.c12, J2.a12, J2.b12, J2.c12, J3.a12, J3.b12, J3.c12, J4.a12, J4.b12, J4.c12, J5.a12, J5.b12, J5.c12, J6.a12, J6.b12, J6.c12, J7.a12, J7.b12, J7.c12, J8.a12, J8.b12, J8.c12
-18V: J1.a9, J1.b9, J1.c9, J2.a9, J2.b9, J2.c9, J3.a9, J3.b9, J3.c9, J4.a9, J4.b9, J4.c9, J5.a9, J5.b9, J5.c9, J6.a9, J6.b9, J6.c9, J7.a9, J7.b9, J7.c9, J8.a9, J8.b9, J8.c9
CLK10M_BUS: J1.c28, J2.c28, J3.c28, J4.c28, J5.c28, J6.c28, J7.c28, J8.c28
ERR1_BUS: J1.c20, J2.c20, J3.c20, J4.c20, J5.c20, J6.c20, J7.c20, J8.c20
ERR2_BUS: J1.c22, J2.c22, J3.c22, J4.c22, J5.c22, J6.c22, J7.c22, J8.c22
FAULT_n: J1.a24, J2.a24, J3.a24, J4.a24, J5.a24, J6.a24, J7.a24, J8.a24
GND: C1.2, D3.1 (A1), J1.a8, J1.a10, J1.a18, J1.a19, J1.a21, J1.a23, J1.a25, J1.a27, J1.a29, J1.b8, J1.b10, J1.b18, J1.b19, J1.b20, J1.b21, J1.b22, J1.b23, J1.b24, J1.b25, J1.b26, J1.b27, J1.b28, J1.b29, J1.b30, J1.b31, J1.b32, J1.c8, J1.c10, J1.c18, J1.c19, J1.c21, J1.c23, J1.c25, J1.c27, J1.c29, J2.a8, J2.a10, J2.a18, J2.a19, J2.a21, J2.a23, J2.a25, J2.a27, J2.a29, J2.b8, J2.b10, J2.b18, J2.b19, J2.b20, J2.b21, J2.b22, J2.b23, J2.b24, J2.b25, J2.b26, J2.b27, J2.b28, J2.b29, J2.b30, J2.b31, J2.b32, J2.c8, J2.c10, J2.c18, J2.c19, J2.c21, J2.c23, J2.c25, J2.c27, J2.c29, J3.a8, J3.a10, J3.a18, J3.a19, J3.a21, J3.a23, J3.a25, J3.a27, J3.a29, J3.b8, J3.b10, J3.b18, J3.b19, J3.b20, J3.b21, J3.b22, J3.b23, J3.b24, J3.b25, J3.b26, J3.b27, J3.b28, J3.b29, J3.b30, J3.b31, J3.b32, J3.c8, J3.c10, J3.c18, J3.c19, J3.c21, J3.c23, J3.c25, J3.c27, J3.c29, J4.a8, J4.a10, J4.a18, J4.a19, J4.a21, J4.a23, J4.a25, J4.a27, J4.a29, J4.b8, J4.b10, J4.b18, J4.b19, J4.b20, J4.b21, J4.b22, J4.b23, J4.b24, J4.b25, J4.b26, J4.b27, J4.b28, J4.b29, J4.b30, J4.b31, J4.b32, J4.c8, J4.c10, J4.c18, J4.c19, J4.c21, J4.c23, J4.c25, J4.c27, J4.c29, J5.a8, J5.a10, J5.a18, J5.a19, J5.a21, J5.a23, J5.a25, J5.a27, J5.a29, J5.b8, J5.b10, J5.b18, J5.b19, J5.b20, J5.b21, J5.b22, J5.b23, J5.b24, J5.b25, J5.b26, J5.b27, J5.b28, J5.b29, J5.b30, J5.b31, J5.b32, J5.c8, J5.c10, J5.c18, J5.c19, J5.c21, J5.c23, J5.c25, J5.c27, J5.c29, J6.a8, J6.a10, J6.a18, J6.a19, J6.a21, J6.a23, J6.a25, J6.a27, J6.a29, J6.b8, J6.b10, J6.b18, J6.b19, J6.b20, J6.b21, J6.b22, J6.b23, J6.b24, J6.b25, J6.b26, J6.b27, J6.b28, J6.b29, J6.b30, J6.b31, J6.b32, J6.c8, J6.c10, J6.c18, J6.c19, J6.c21, J6.c23, J6.c25, J6.c27, J6.c29, J7.a8, J7.a10, J7.a18, J7.a19, J7.a21, J7.a23, J7.a25, J7.a27, J7.a29, J7.b8, J7.b10, J7.b18, J7.b19, J7.b20, J7.b21, J7.b22, J7.b23, J7.b24, J7.b25, J7.b26, J7.b27, J7.b28, J7.b29, J7.b30, J7.b31, J7.b32, J7.c8, J7.c10, J7.c18, J7.c19, J7.c21, J7.c23, J7.c25, J7.c27, J7.c29, J8.a8, J8.a10, J8.a18, J8.a19, J8.a21, J8.a23, J8.a25, J8.a27, J8.a29, J8.b8, J8.b10, J8.b18, J8.b19, J8.b20, J8.b21, J8.b22, J8.b23, J8.b24, J8.b25, J8.b26, J8.b27, J8.b28, J8.b29, J8.b30, J8.b31, J8.b32, J8.c8, J8.c10, J8.c18, J8.c19, J8.c21, J8.c23, J8.c25, J8.c27, J8.c29, R1.2
MOD1_BUS: J1.c24, J2.c24, J3.c24, J4.c24, J5.c24, J6.c24, J7.c24, J8.c24
MOD2_BUS: J1.c26, J2.c26, J3.c26, J4.c26, J5.c26, J6.c26, J7.c26, J8.c26
PGND_TEC: C1.1, D3.2 (A2), J1.a3, J1.a4, J1.b3, J1.b4, J1.c3, J1.c4, J2.a3, J2.a4, J2.b3, J2.b4, J2.c3, J2.c4, J3.a3, J3.a4, J3.b3, J3.b4, J3.c3, J3.c4, J4.a3, J4.a4, J4.b3, J4.b4, J4.c3, J4.c4, J5.a3, J5.a4, J5.b3, J5.b4, J5.c3, J5.c4, J6.a3, J6.a4, J6.b3, J6.b4, J6.c3, J6.c4, J7.a3, J7.a4, J7.b3, J7.b4, J7.c3, J7.c4, J8.a3, J8.a4, J8.b3, J8.b4, J8.c3, J8.c4, R1.1
SCL_BUS: J1.a28, J2.a28, J3.a28, J4.a28, J5.a28, J6.a28, J7.a28, J8.a28
SDA_BUS: J1.a26, J2.a26, J3.a26, J4.a26, J5.a26, J6.a26, J7.a26, J8.a26
SPARE_A30: J1.a30, J2.a30, J3.a30, J4.a30, J5.a30, J6.a30, J7.a30, J8.a30
SPARE_A31: J1.a31, J2.a31, J3.a31, J4.a31, J5.a31, J6.a31, J7.a31, J8.a31
SPARE_A32: J1.a32, J2.a32, J3.a32, J4.a32, J5.a32, J6.a32, J7.a32, J8.a32
SPARE_C30: J1.c30, J2.c30, J3.c30, J4.c30, J5.c30, J6.c30, J7.c30, J8.c30
SPARE_C31: J1.c31, J2.c31, J3.c31, J4.c31, J5.c31, J6.c31, J7.c31, J8.c31
SPARE_C32: J1.c32, J2.c32, J3.c32, J4.c32, J5.c32, J6.c32, J7.c32, J8.c32
VREF_MID: J1.a22, J2.a22, J3.a22, J4.a22, J5.a22, J6.a22, J7.a22, J8.a22

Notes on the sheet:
pm22V (FABBED): P5-P8 only. pm6V (FABBED): P1-P4 only. Both slot-agnostic as built.
DIG: I2C master (SDA/SCL); drives MOD1/2 from DDS; ADC-listens ERR1/2;
2. TEC current returns ONLY on P2/P4 (PGND_TEC); joined to GND at single star point at pm6V output.
8. LO and 10 MHz distribution via front-panel coax; c20 SPARE_CLK10M is fallback only.
AFE: drives ERR1 + ERR2; local I2C ADC for PD monitors; LO1/LO2 in via front SMA;
6. GND at c15 guards ERR/MOD group; GA straps are DC - safe next to analog.
38.1 mm AAVID 531102B extruded (pm6V/pm22V/pm1p8V); ~35 mm D18 radial caps (typ, VERIFY)
TEC power from P1-P4 (returns ONLY on PGND_TEC); laser head conn on front panel.
slot 5: GA2=1 GA1=0 GA0=0 (e.g. AFE)
slot 3: GA2=0 GA1=1 GA0=0 (e.g. pm1p8V - ignores GA)
PER-CARD PIN USAGE (all cards carry the same connector):
any card in any slot; slot identity via GA2..GA0 straps on the backplane
Budget at 10HP: 50.8 - 1.6 PCB - 2.5 neighbour solder-side = 46.7 mm envelope
(any-card-any-slot requires one pitch). 8 x 10HP = 80HP -> standard 84HP 3U subrack, 4HP spare.
1. Rail bus a13-b17 + blades P1-P8 match pm1p8V/pm6V/pm22V as built - fabbed boards unchanged.
slot 6: GA2=1 GA1=0 GA0=1 (e.g. CH: GA0=1 -> laser 1 nets)
slot 7: GA2=1 GA1=1 GA0=0 (e.g. CH: GA0=0 -> laser 2 nets)
bus is STATIC during lock (quiet mode) - poll telemetry <= 10 Hz, never during acquisition.
8HP (40.64) DOES NOT FIT. Caliper-check 6223BG stack + D18 cap heights on fabbed boards.
slot 4: GA2=0 GA1=1 GA0=1 (e.g. DIG - I2C master)
4. Keep dither/mod frequency away from N x 100/400 kHz (I2C harmonics fold through PDH demod).
slot 8: GA2=1 GA1=1 GA0=1 (spare)
Tallest components above PCB (measured from footprints/descriptions):
MECHANICAL - SLOT PITCH (2026-07-15):
GA STRAPPING (per backplane slot; 0 = GND, 1 = 3V3): Set on each card with jumpers.
local I2C DAC (setpoints) + I2C ADC (IMON/NTC/MPD) at GA-derived address;
39.1 mm GBPC bridge (7.3) + Boyd 6223BG sink (31.75) - pm22V/pm6V <- sets the pitch
DESIGN RULES / NOTES (draft 2026-07-15):
25.4 mm Wakefield 657-10ABPE (pm6V; -10 variant chosen to fit eurocard)
9. On CH/AFE cards: RC-filter DAC outputs (<=1 kHz), 10R+10uF on I2C-chip 3V3,
digital cluster in the connector corner, away from summing nodes / sense amps.
-> 7.6 mm air over tallest sink (natural-convection rated; fins vertical = chimney per bay).
7. FAULT_n: open-drain wired-OR, any card may assert; DIG queries source over I2C.
Connector pitch = 10 HP = 50.8 mm centre-to-centre, UNIFORM across all 8 slots
slot 2: GA2=0 GA1=0 GA0=1 (e.g. pm6V - ignores GA)
monitors all rails incl. blades; FAULT_n pull-up + read; front: USB, TFT, 10MHz SMA, LO SMAs.
CH x2 (identical): GA0 selects ERR1/MOD1 vs ERR2/MOD2 via on-card ADG419;
slot 1: GA2=0 GA1=0 GA0=0 (e.g. pm22V - ignores GA)
UNIVERSAL SLOT - every backplane position wired identically (DIN 41612 Type M 24+8)
fiber FC receptacles on front panel.

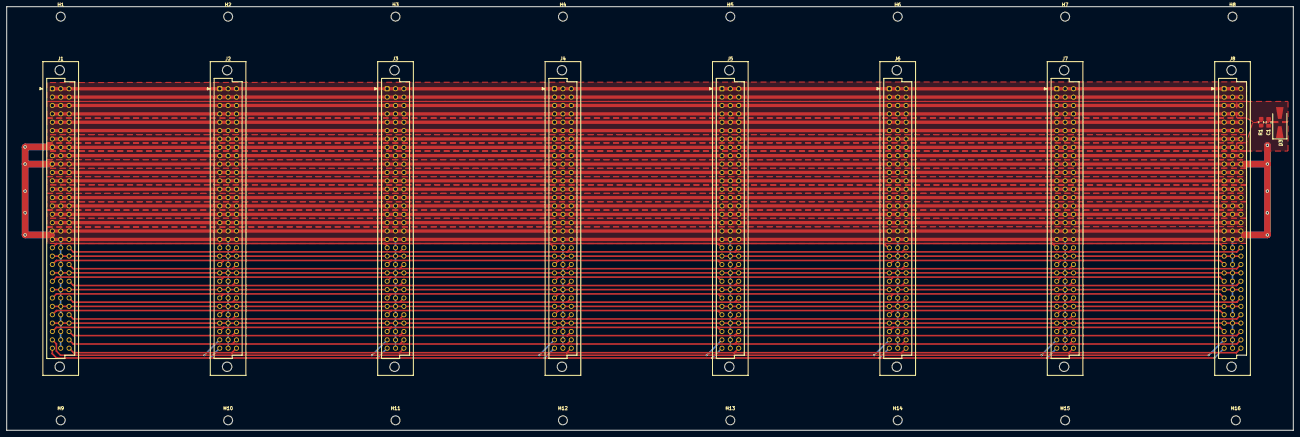
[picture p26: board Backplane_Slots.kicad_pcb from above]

Board: 2 copper layers, 390.4 x 128.6 mm, 27 parts (0 on the bottom side), 29 nets.

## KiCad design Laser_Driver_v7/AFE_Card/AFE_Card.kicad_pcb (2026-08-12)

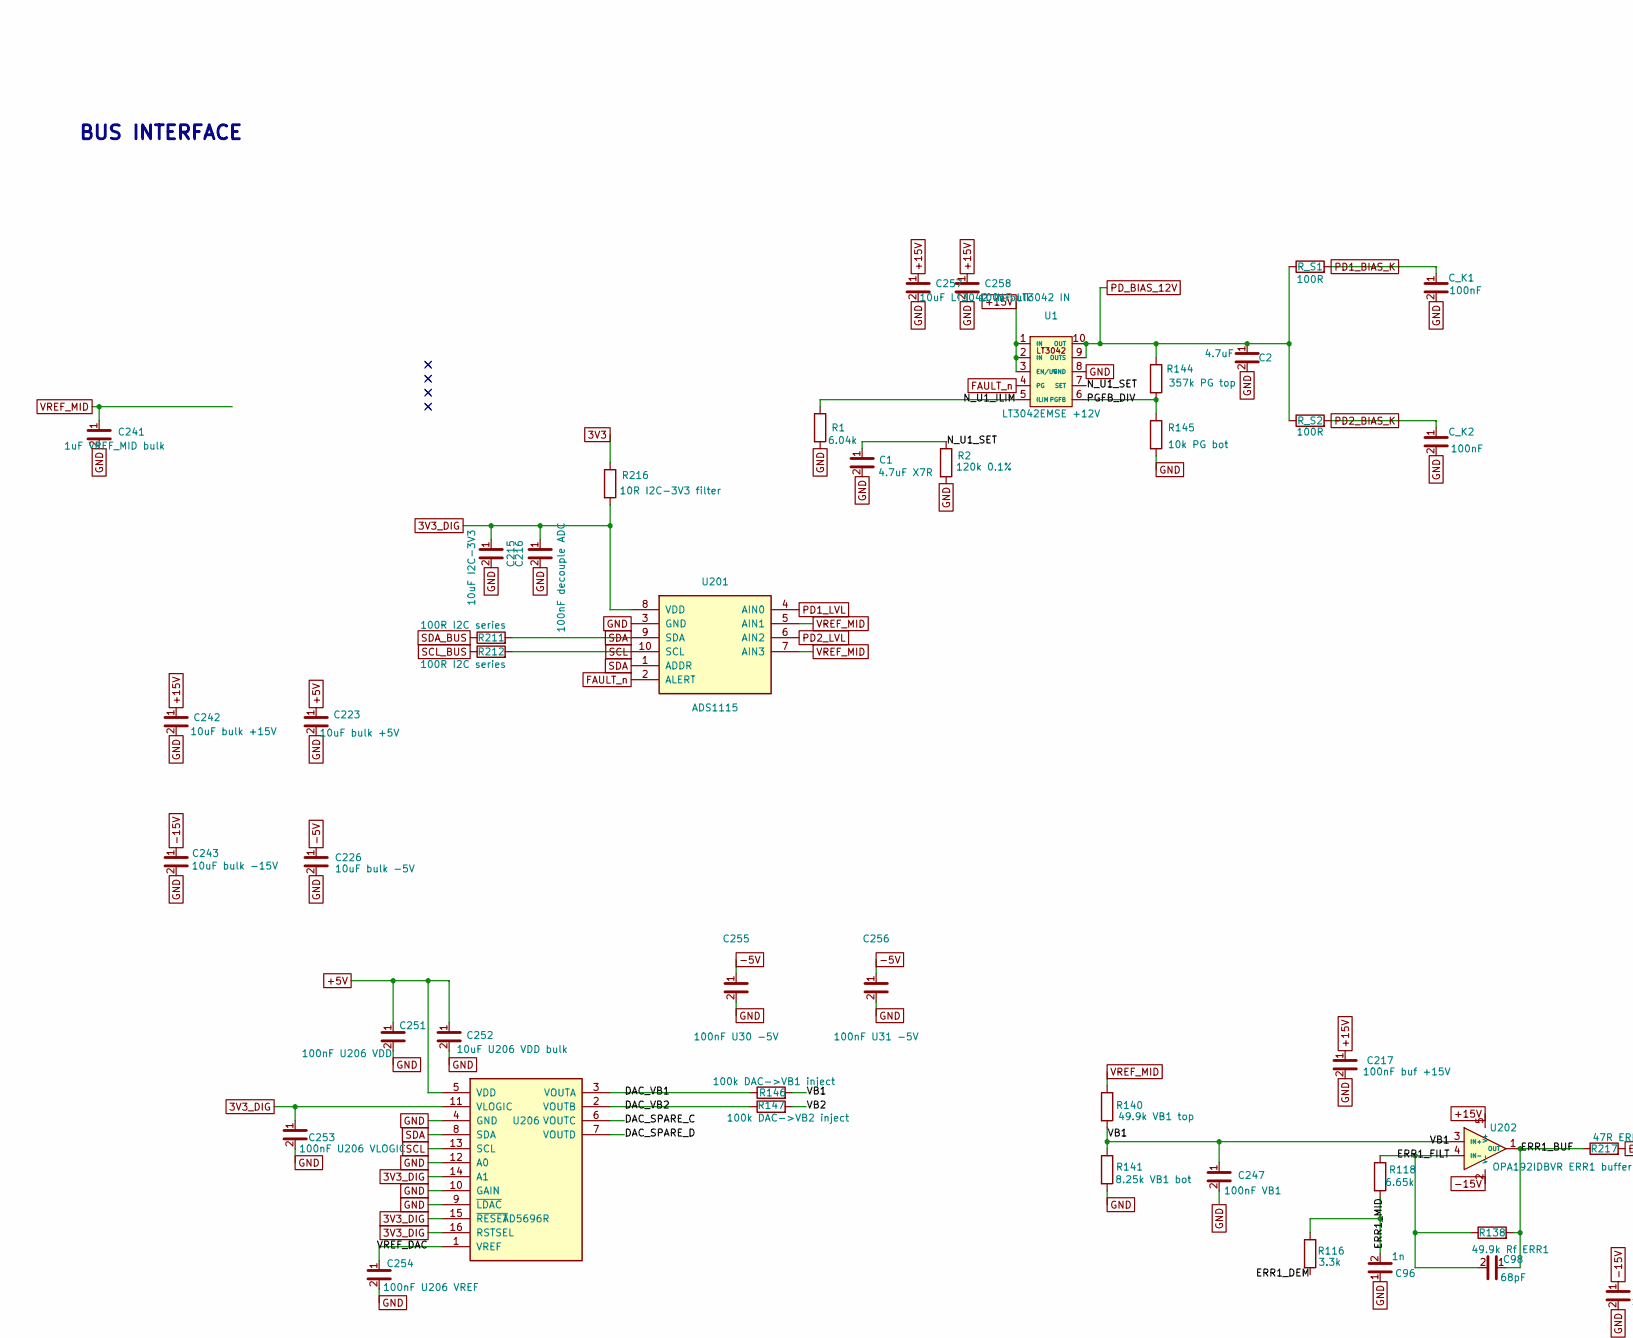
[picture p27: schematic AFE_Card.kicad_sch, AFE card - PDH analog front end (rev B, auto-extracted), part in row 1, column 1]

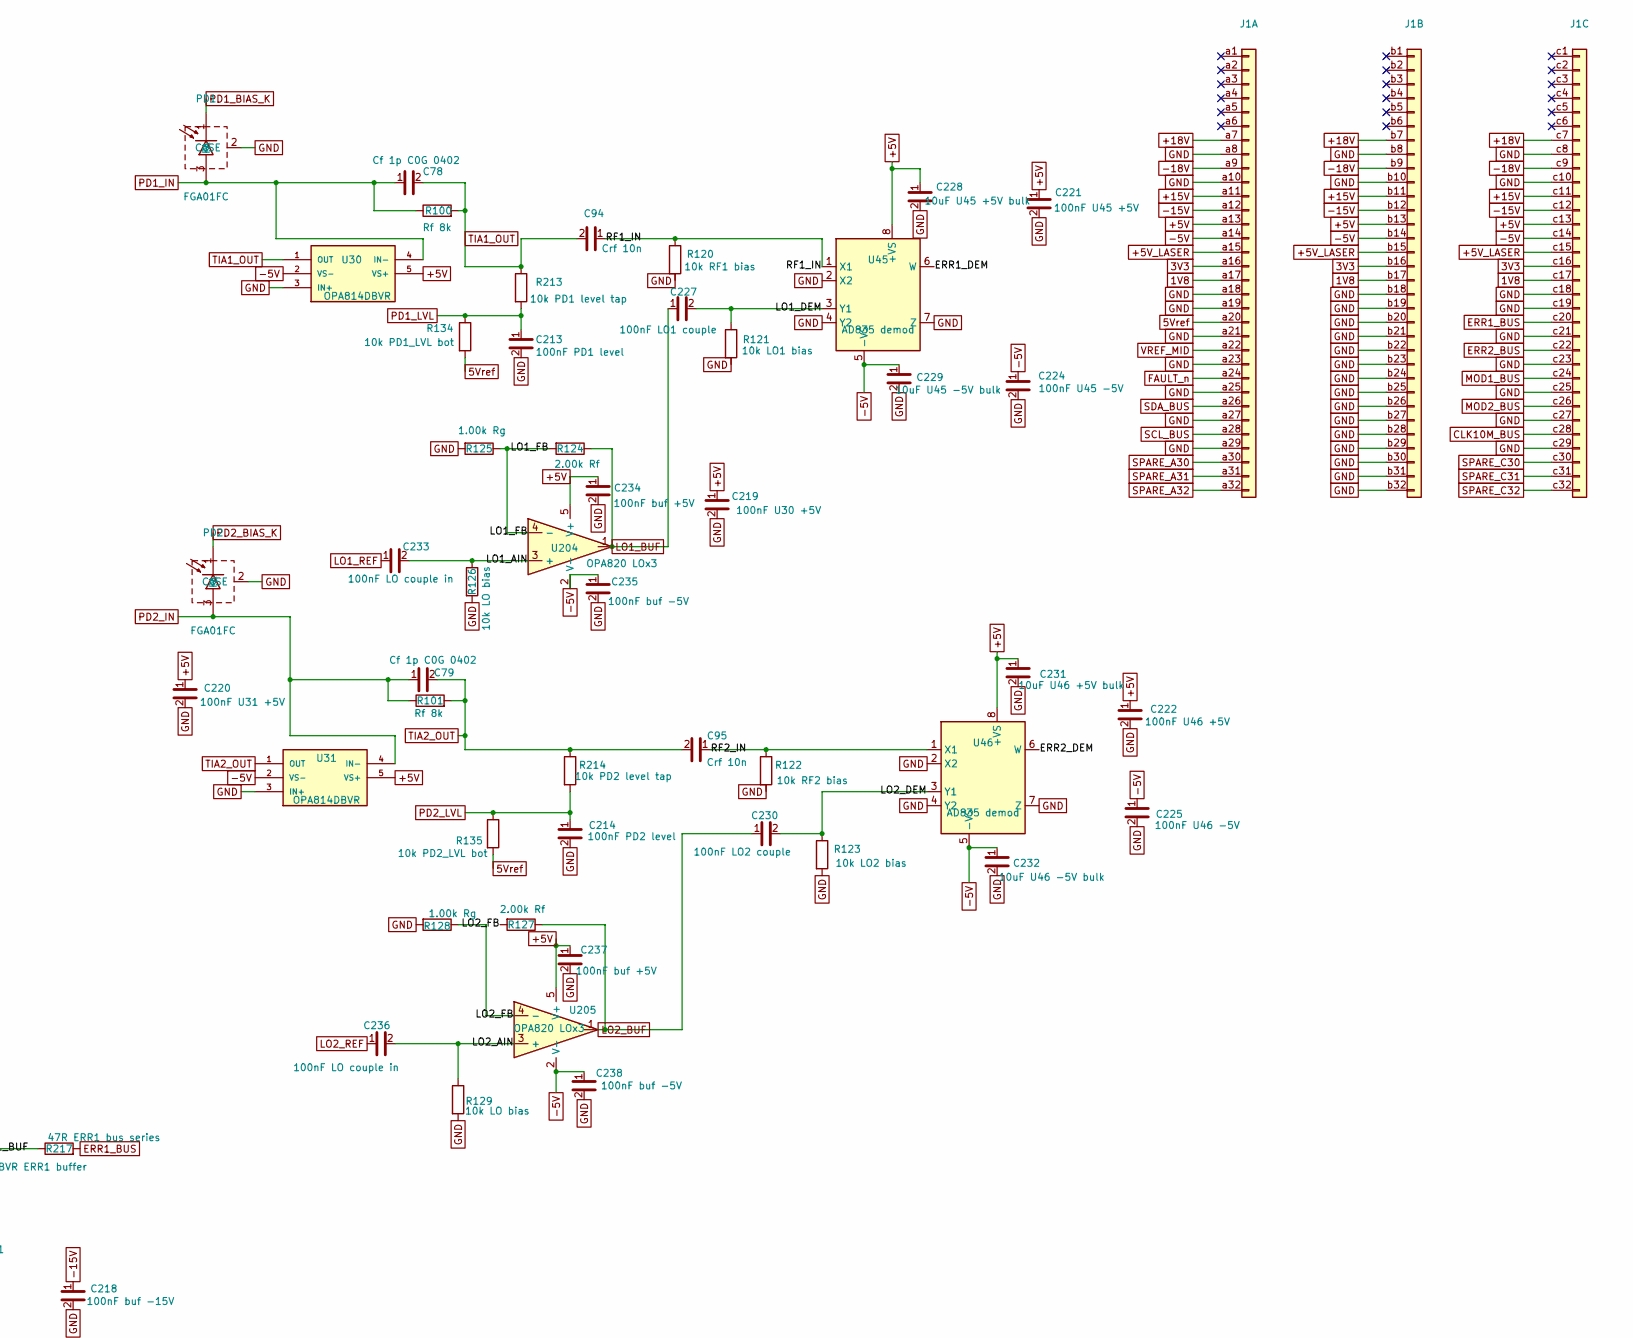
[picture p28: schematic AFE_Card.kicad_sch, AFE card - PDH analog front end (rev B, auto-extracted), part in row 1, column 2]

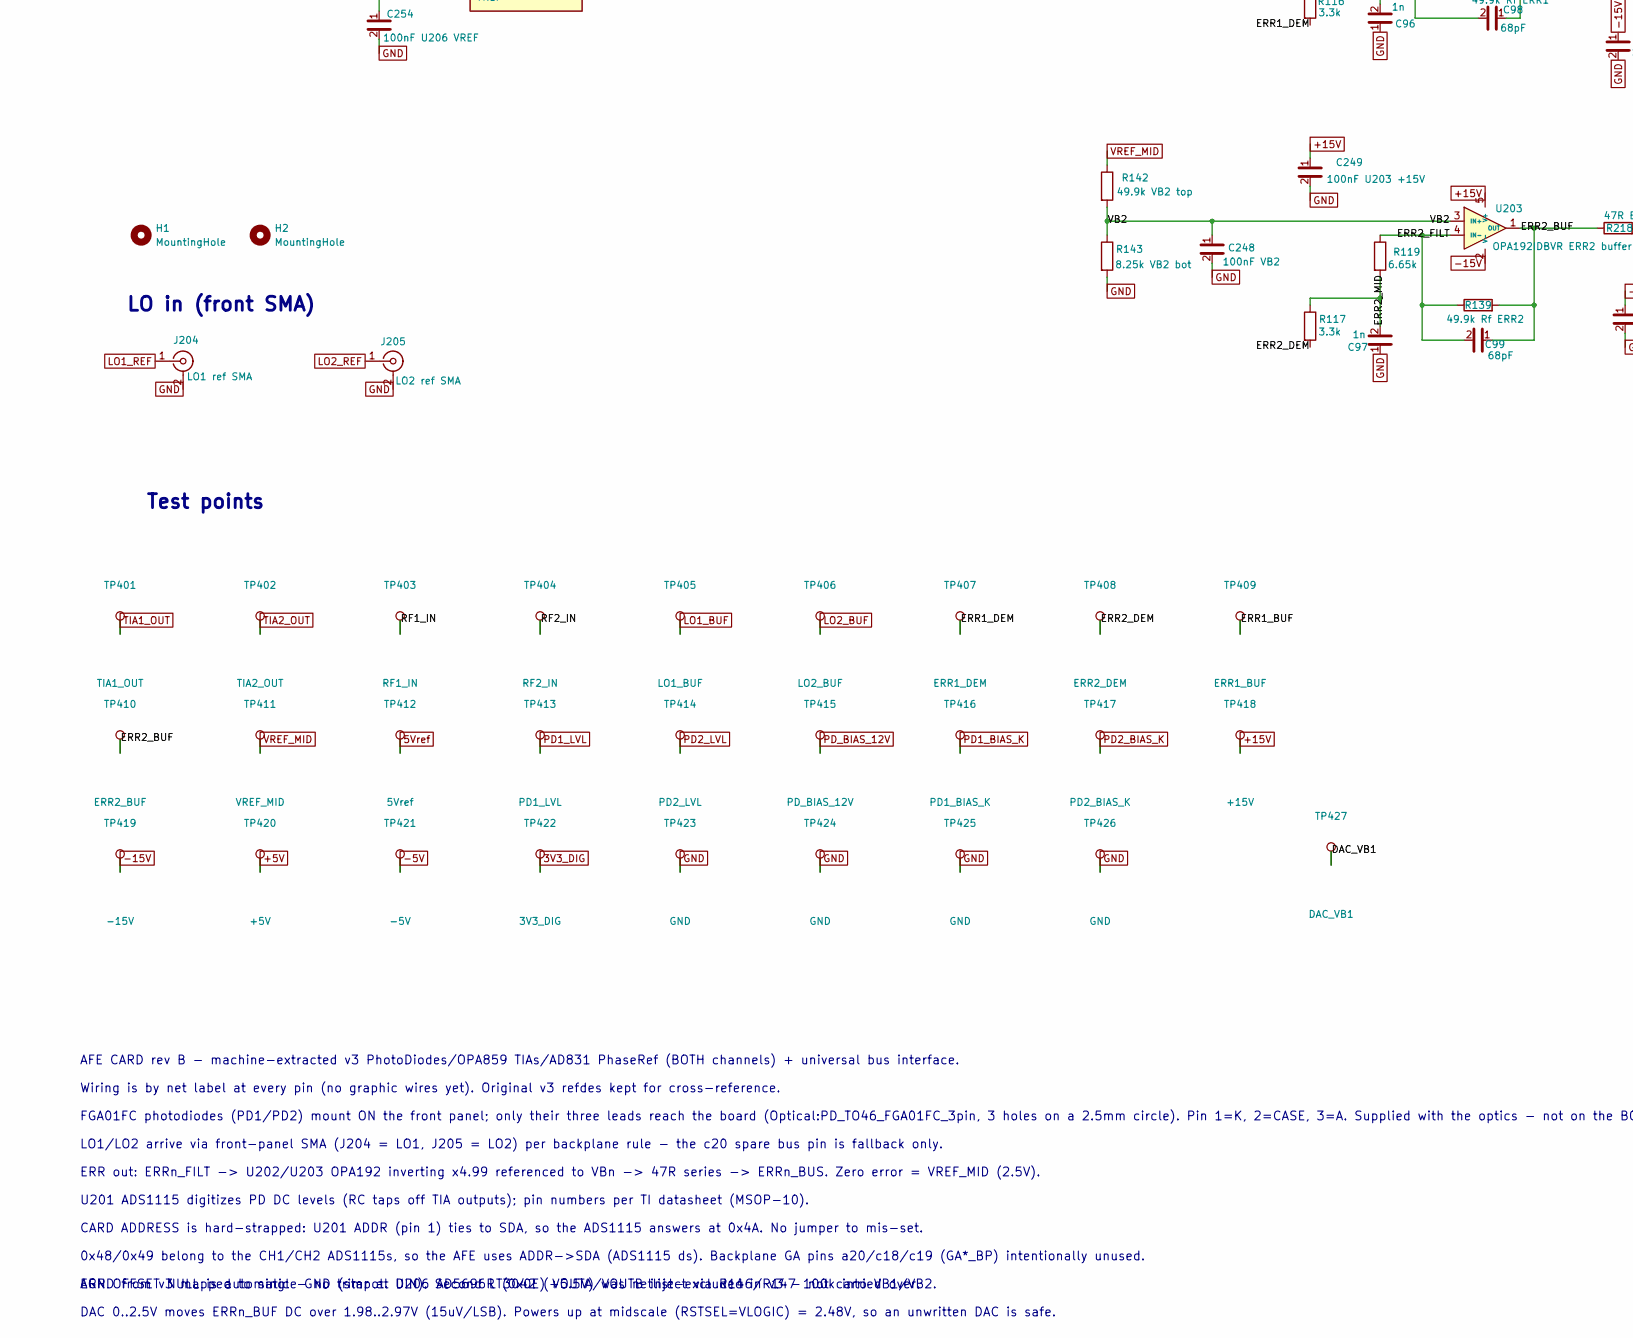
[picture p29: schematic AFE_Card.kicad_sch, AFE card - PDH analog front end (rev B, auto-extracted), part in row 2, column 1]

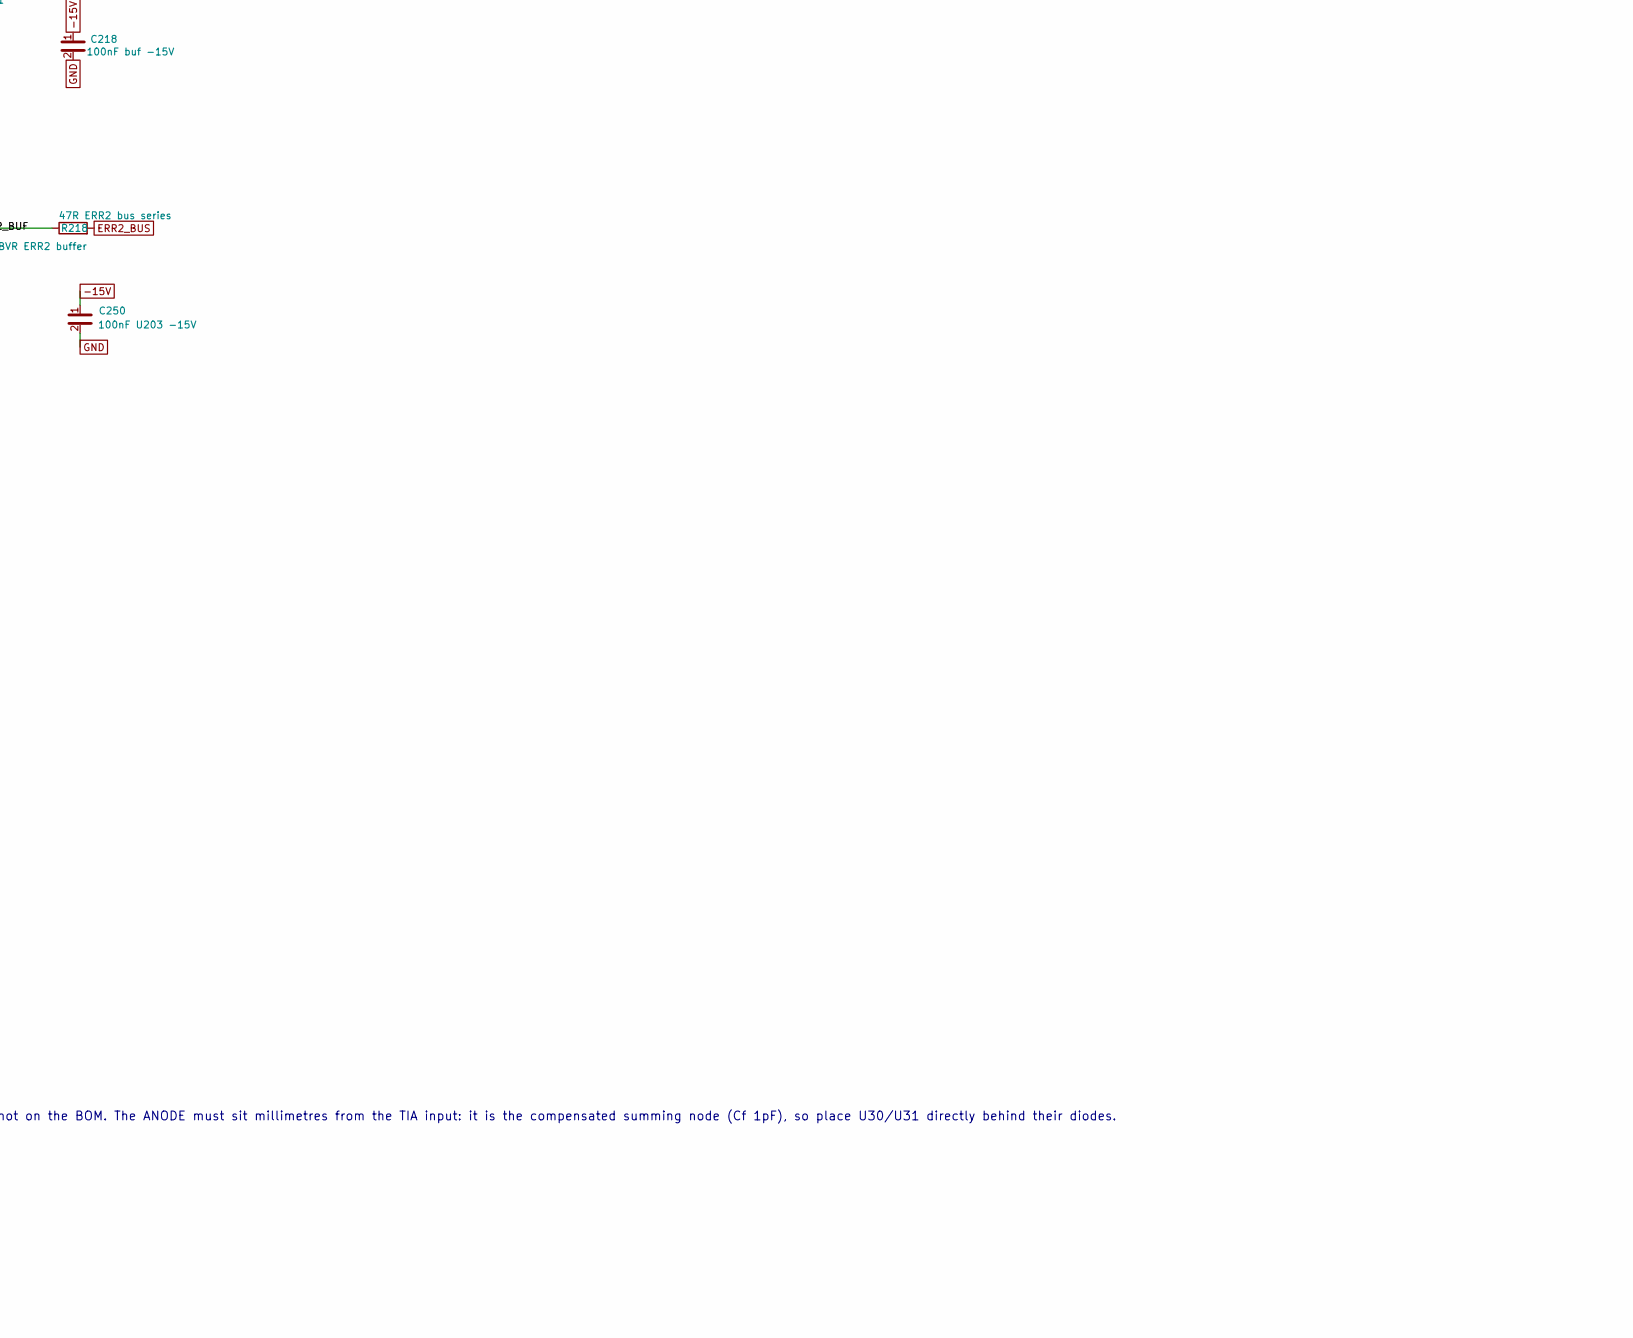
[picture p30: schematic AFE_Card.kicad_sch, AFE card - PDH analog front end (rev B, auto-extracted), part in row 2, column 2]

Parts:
C1: 4.7uF X7R; C_0805_2012Metric_Pad1.18x1.45mm_HandSolder
C2: 4.7uF; C_0805_2012Metric_Pad1.18x1.45mm_HandSolder
C78, C79: Cf 1p C0G 0402; C_0402_1005Metric_Pad0.74x0.62mm_HandSolder
C94, C95: Crf 10n; C_0805_2012Metric_Pad1.18x1.45mm_HandSolder
C96, C97: 1n; C_0805_2012Metric_Pad1.18x1.45mm_HandSolder
C98, C99: 68pF; C_0805_2012Metric_Pad1.18x1.45mm_HandSolder
C213: 100nF PD1 level; C_0805_2012Metric_Pad1.18x1.45mm_HandSolder
C214: 100nF PD2 level; C_0805_2012Metric_Pad1.18x1.45mm_HandSolder
C215: 10uF I2C-3V3; C_0805_2012Metric_Pad1.18x1.45mm_HandSolder
C216: 100nF decouple ADC; C_0805_2012Metric_Pad1.18x1.45mm_HandSolder
C217: 100nF buf +15V; C_0805_2012Metric_Pad1.18x1.45mm_HandSolder
C218: 100nF buf -15V; C_0805_2012Metric_Pad1.18x1.45mm_HandSolder
C219: 100nF U30 +5V; C_0805_2012Metric_Pad1.18x1.45mm_HandSolder
C220: 100nF U31 +5V; C_0805_2012Metric_Pad1.18x1.45mm_HandSolder
C221: 100nF U45 +5V; C_0805_2012Metric_Pad1.18x1.45mm_HandSolder
C222: 100nF U46 +5V; C_0805_2012Metric_Pad1.18x1.45mm_HandSolder
C223: 10uF bulk +5V; C_0805_2012Metric_Pad1.18x1.45mm_HandSolder
C224: 100nF U45 -5V; C_0805_2012Metric_Pad1.18x1.45mm_HandSolder
C225: 100nF U46 -5V; C_0805_2012Metric_Pad1.18x1.45mm_HandSolder
C226: 10uF bulk -5V; C_0805_2012Metric_Pad1.18x1.45mm_HandSolder
C227: 100nF LO1 couple; C_0805_2012Metric_Pad1.18x1.45mm_HandSolder
C228: 10uF U45 +5V bulk; C_0805_2012Metric_Pad1.18x1.45mm_HandSolder
C229: 10uF U45 -5V bulk; C_0805_2012Metric_Pad1.18x1.45mm_HandSolder
C230: 100nF LO2 couple; C_0805_2012Metric_Pad1.18x1.45mm_HandSolder
C231: 10uF U46 +5V bulk; C_0805_2012Metric_Pad1.18x1.45mm_HandSolder
C232: 10uF U46 -5V bulk; C_0805_2012Metric_Pad1.18x1.45mm_HandSolder
C233, C236: 100nF LO couple in; C_0805_2012Metric_Pad1.18x1.45mm_HandSolder
C234, C237: 100nF buf +5V; C_0805_2012Metric_Pad1.18x1.45mm_HandSolder
C235, C238: 100nF buf -5V; C_0805_2012Metric_Pad1.18x1.45mm_HandSolder
C241: 1uF VREF_MID bulk; C_0805_2012Metric_Pad1.18x1.45mm_HandSolder
C242: 10uF bulk +15V; C_0805_2012Metric_Pad1.18x1.45mm_HandSolder
C243: 10uF bulk -15V; C_0805_2012Metric_Pad1.18x1.45mm_HandSolder
C247: 100nF VB1; C_0805_2012Metric_Pad1.18x1.45mm_HandSolder
C248: 100nF VB2; C_0805_2012Metric_Pad1.18x1.45mm_HandSolder
C249: 100nF U203 +15V; C_0805_2012Metric_Pad1.18x1.45mm_HandSolder
C250: 100nF U203 -15V; C_0805_2012Metric_Pad1.18x1.45mm_HandSolder
C251: 100nF U206 VDD; C_0805_2012Metric_Pad1.18x1.45mm_HandSolder
C252: 10uF U206 VDD bulk; C_0805_2012Metric_Pad1.18x1.45mm_HandSolder
C253: 100nF U206 VLOGIC; C_0805_2012Metric_Pad1.18x1.45mm_HandSolder
C254: 100nF U206 VREF; C_0805_2012Metric_Pad1.18x1.45mm_HandSolder
C255: 100nF U30 -5V; C_0805_2012Metric_Pad1.18x1.45mm_HandSolder
C256: 100nF U31 -5V; C_0805_2012Metric_Pad1.18x1.45mm_HandSolder
C257: 10uF LT3042 IN bulk; C_0805_2012Metric_Pad1.18x1.45mm_HandSolder
C258: 100nF LT3042 IN; C_0805_2012Metric_Pad1.18x1.45mm_HandSolder
C_K1, C_K2: 100nF; C_0805_2012Metric_Pad1.18x1.45mm_HandSolder
H1, H2: MountingHole; MountingHole_2.7mm
J1: DIN41612_03x32_C_Split; DIN41612_C_3x32_Male_Horizontal_THT
J204: LO1 ref SMA; SMA_Amphenol_132203-12_Horizontal
J205: LO2 ref SMA; SMA_Amphenol_132203-12_Horizontal
PD1, PD2: FGA01FC; PD_FGA01FC_EdgeBracket
R1: 6.04k; R_0805_2012Metric_Pad1.20x1.40mm_HandSolder
R2: 120k 0.1%; R_0805_2012Metric_Pad1.20x1.40mm_HandSolder
R100, R101: Rf 8k; R_0805_2012Metric_Pad1.20x1.40mm_HandSolder
R116, R117: 3.3k; R_0805_2012Metric_Pad1.20x1.40mm_HandSolder
R118, R119: 6.65k; R_0805_2012Metric_Pad1.20x1.40mm_HandSolder
R120: 10k RF1 bias; R_0805_2012Metric_Pad1.20x1.40mm_HandSolder
R121: 10k LO1 bias; R_0805_2012Metric_Pad1.20x1.40mm_HandSolder
R122: 10k RF2 bias; R_0805_2012Metric_Pad1.20x1.40mm_HandSolder
R123: 10k LO2 bias; R_0805_2012Metric_Pad1.20x1.40mm_HandSolder
R124, R127: 2.00k Rf; R_0805_2012Metric_Pad1.20x1.40mm_HandSolder
R125, R128: 1.00k Rg; R_0805_2012Metric_Pad1.20x1.40mm_HandSolder
R126, R129: 10k LO bias; R_0805_2012Metric_Pad1.20x1.40mm_HandSolder
R134: 10k PD1_LVL bot; R_0805_2012Metric_Pad1.20x1.40mm_HandSolder
R135: 10k PD2_LVL bot; R_0805_2012Metric_Pad1.20x1.40mm_HandSolder
R138: 49.9k Rf ERR1; R_0805_2012Metric_Pad1.20x1.40mm_HandSolder
R139: 49.9k Rf ERR2; R_0805_2012Metric_Pad1.20x1.40mm_HandSolder
R140: 49.9k VB1 top; R_0805_2012Metric_Pad1.20x1.40mm_HandSolder
R141: 8.25k VB1 bot; R_0805_2012Metric_Pad1.20x1.40mm_HandSolder
R142: 49.9k VB2 top; R_0805_2012Metric_Pad1.20x1.40mm_HandSolder
R143: 8.25k VB2 bot; R_0805_2012Metric_Pad1.20x1.40mm_HandSolder
R144: 357k PG top; R_0805_2012Metric_Pad1.20x1.40mm_HandSolder
R145: 10k PG bot; R_0805_2012Metric_Pad1.20x1.40mm_HandSolder
R146: 100k DAC->VB1 inject; R_0805_2012Metric_Pad1.20x1.40mm_HandSolder
R147: 100k DAC->VB2 inject; R_0805_2012Metric_Pad1.20x1.40mm_HandSolder
R211, R212: 100R I2C series; R_0805_2012Metric_Pad1.20x1.40mm_HandSolder
R213: 10k PD1 level tap; R_0805_2012Metric_Pad1.20x1.40mm_HandSolder
R214: 10k PD2 level tap; R_0805_2012Metric_Pad1.20x1.40mm_HandSolder
R216: 10R I2C-3V3 filter; R_0805_2012Metric_Pad1.20x1.40mm_HandSolder
R217: 47R ERR1 bus series; R_0805_2012Metric_Pad1.20x1.40mm_HandSolder
R218: 47R ERR2 bus series; R_0805_2012Metric_Pad1.20x1.40mm_HandSolder
R_S1, R_S2: 100R; R_0805_2012Metric_Pad1.20x1.40mm_HandSolder
TP401: TIA1_OUT; TestPoint_Pad_D1.0mm
TP402: TIA2_OUT; TestPoint_Pad_D1.0mm
TP403: RF1_IN; TestPoint_Pad_D1.0mm
TP404: RF2_IN; TestPoint_Pad_D1.0mm
TP405: LO1_BUF; TestPoint_Pad_D1.0mm
TP406: LO2_BUF; TestPoint_Pad_D1.0mm
TP407: ERR1_DEM; TestPoint_Pad_D1.0mm
TP408: ERR2_DEM; TestPoint_Pad_D1.0mm
TP409: ERR1_BUF; TestPoint_Pad_D1.0mm
TP410: ERR2_BUF; TestPoint_Pad_D1.0mm
TP411: VREF_MID; TestPoint_Pad_D1.0mm
TP412: 5Vref; TestPoint_Pad_D1.0mm
TP413: PD1_LVL; TestPoint_Pad_D1.0mm
TP414: PD2_LVL; TestPoint_Pad_D1.0mm
TP415: PD_BIAS_12V; TestPoint_Pad_D1.0mm
TP416: PD1_BIAS_K; TestPoint_Pad_D1.0mm
TP417: PD2_BIAS_K; TestPoint_Pad_D1.0mm
TP418: +15V; TestPoint_Pad_D1.0mm
TP419: -15V; TestPoint_Pad_D1.0mm
TP420: +5V; TestPoint_Pad_D1.0mm
TP421: -5V; TestPoint_Pad_D1.0mm
TP422: 3V3_DIG; TestPoint_Pad_D1.0mm
TP423, TP424, TP425, TP426: GND; TestPoint_THTPad_D1.5mm_Drill0.7mm
TP427: DAC_VB1; TestPoint_Pad_D1.0mm
U1: LT3042EMSE +12V; MSOP-10-1EP_3x3mm_P0.5mm_EP1.68x1.88mm
U30, U31: OPA814DBVR; MOUSER_PART_NUMBER 595-OPA814DBVR
U45, U46: AD835 demod; SOIC-8_3.9x4.9mm_P1.27mm
U201: ADS1115; MSOP-10_3x3mm_P0.5mm
U202: OPA192IDBVR ERR1 buffer; SOT-23-5
U203: OPA192IDBVR ERR2 buffer; SOT-23-5
U204, U205: OPA820 LOx3; SOT-23-5
U206: AD5696R; TSSOP-16_4.4x5mm_P0.65mm

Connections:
1V8: J1.a17, J1.b17, J1.c17
3V3: J1.a16, J1.b16, J1.c16, R216.1
3V3_DIG: C215.1, C216.1, C253.1, R216.2, TP422.1 (1_1), U201.8 (VDD), U206.11 (VLOGIC), U206.14 (A1), U206.15 (~RESET), U206.16 (RSTSEL)
5Vref: J1.a20, R134.2, R135.2, TP412.1 (1_1)
+5V: C219.1, C220.1, C221.1, C222.1, C223.1, C228.1, C231.1, C234.1, C237.1, C251.1, C252.1, J1.a13, J1.b13, J1.c13, TP420.1 (1_1), U30.5 (VS+), U31.5 (VS+), U45.8 (+VS), U46.8 (+VS), U204.5 (V+), U205.5 (V+), U206.5 (VDD)
+5V_LASER: J1.a15, J1.b15, J1.c15
+15V: C217.1, C242.1, C249.1, C257.1, C258.1, J1.a11, J1.b11, J1.c11, TP418.1 (1_1), U1.1 (IN), U1.2 (IN), U1.3 (EN/UV), U202.5 (V+), U203.5 (V+)
+18V: J1.a7, J1.b7, J1.c7
-5V: C224.1, C225.1, C226.1, C229.1, C232.1, C235.1, C238.1, C255.1, C256.1, J1.a14, J1.b14, J1.c14, TP421.1 (1_1), U30.2 (VS-), U31.2 (VS-), U45.5 (-VS), U46.5 (-VS), U204.2 (V-), U205.2 (V-)
-15V: C218.1, C243.1, C250.1, J1.a12, J1.b12, J1.c12, TP419.1 (1_1), U202.2 (V-), U203.2 (V-)
-18V: J1.a9, J1.b9, J1.c9
/DAC_SPARE_C: U206.6 (VOUTC)
/DAC_SPARE_D: U206.7 (VOUTD)
/DAC_VB1: R146.1, TP427.1 (1_1), U206.3 (VOUTA)
/DAC_VB2: R147.1, U206.2 (VOUTB)
/ERR1_BUF: C98.1, R138.2, R217.1, TP409.1 (1_1), U202.1 (OUT)
/ERR1_DEM: R116.2, TP407.1 (1_1), U45.6 (W)
/ERR1_FILT: C98.2, R118.1, R138.1, U202.4 (IN-)
/ERR1_MID: C96.2, R116.1, R118.2
/ERR2_BUF: C99.1, R139.2, R218.1, TP410.1 (1_1), U203.1 (OUT)
/ERR2_DEM: R117.2, TP408.1 (1_1), U46.6 (W)
/ERR2_FILT: C99.2, R119.1, R139.1, U203.4 (IN-)
/ERR2_MID: C97.2, R117.1, R119.2
/LO1_AIN: C233.2, R126.1, U204.3 (+)
/LO1_DEM: C227.2, R121.1, U45.3 (Y1)
/LO1_FB: R124.2, R125.1, U204.4 (-)
/LO2_AIN: C236.2, R129.1, U205.3 (+)
/LO2_DEM: C230.2, R123.1, U46.3 (Y1)
/LO2_FB: R127.2, R128.1, U205.4 (-)
/N_U1_ILIM: R1.1, U1.5 (ILIM)
/N_U1_SET: C1.1, R2.1, U1.7 (SET)
/PGFB_DIV: R144.2, R145.1, U1.6 (PGFB)
/RF1_IN: C94.1, R120.1, TP403.1 (1_1), U45.1 (X1)
/RF2_IN: C95.1, R122.1, TP404.1 (1_1), U46.1 (X1)
/VB1: C247.1, R140.2, R141.1, R146.2, U202.3 (IN+)
/VB2: C248.1, R142.2, R143.1, R147.2, U203.3 (IN+)
/VREF_DAC: C254.1, U206.1 (VREF)
CLK10M_BUS: J1.c28
ERR1_BUS: J1.c20, R217.2
ERR2_BUS: J1.c22, R218.2
FAULT_n: J1.a24, U1.4 (PG), U201.2 (ALERT)
GND: C1.2, C2.2, C96.1, C97.1, C213.2, C214.2, C215.2, C216.2, C217.2, C218.2, C219.2, C220.2, C221.2, C222.2, C223.2, C224.2, C225.2, C226.2, C228.2, C229.2, C231.2, C232.2, C234.2, C235.2, C237.2, C238.2, C241.2, C242.2, C243.2, C247.2, C248.2, C249.2, C250.2, C251.2, C252.2, C253.2, C254.2, C255.2, C256.2, C257.2, C258.2, C_K1.2, C_K2.2, J1.a8, J1.a10, J1.a18, J1.a19, J1.a21, J1.a23, J1.a25, J1.a27, J1.a29, J1.b8, J1.b10, J1.b18, J1.b19, J1.b20, J1.b21, J1.b22, J1.b23, J1.b24, J1.b25, J1.b26, J1.b27, J1.b28, J1.b29, J1.b30, J1.b31, J1.b32, J1.c8, J1.c10, J1.c18, J1.c19, J1.c21, J1.c23, J1.c25, J1.c27, J1.c29, J204.2 (Ext), J205.2 (Ext), PD1.2 (CASE), PD2.2 (CASE), R1.2, R2.2, R120.2, R121.2, R122.2, R123.2, R125.2, R126.2, R128.2, R129.2, R141.2, R143.2, R145.2, TP423.1 (1_1), TP424.1 (1_1), TP425.1 (1_1), TP426.1 (1_1), U1.8 (GND), U1.11 (Pad), U30.3 (IN+), U31.3 (IN+), U45.2 (X2), U45.4 (Y2), U45.7 (Z), U46.2 (X2), U46.4 (Y2), U46.7 (Z), U201.3 (GND), U206.4 (GND), U206.9 (~LDAC), U206.10 (GAIN), U206.12 (A0)
LO1_BUF: C227.1, R124.1, TP405.1 (1_1), U204.1
LO1_REF: C233.1, J204.1 (In)
LO2_BUF: C230.1, R127.1, TP406.1 (1_1), U205.1
LO2_REF: C236.1, J205.1 (In)
MOD1_BUS: J1.c24
MOD2_BUS: J1.c26
PD1_BIAS_K: C_K1.1, PD1.1 (K), R_S1.2, TP416.1 (1_1)
PD1_IN: C78.1, PD1.3 (A), R100.1, U30.4 (IN-)
PD1_LVL: C213.1, R134.1, R213.2, TP413.1 (1_1), U201.4 (AIN0)
PD2_BIAS_K: C_K2.1, PD2.1 (K), R_S2.2, TP417.1 (1_1)
PD2_IN: C79.1, PD2.3 (A), R101.1, U31.4 (IN-)
PD2_LVL: C214.1, R135.1, R214.2, TP414.1 (1_1), U201.6 (AIN2)
PD_BIAS_12V: C2.1, R144.1, R_S1.1, R_S2.1, TP415.1 (1_1), U1.9 (OUTS), U1.10 (OUT)
SCL: R212.2, U201.10 (SCL), U206.13 (SCL)
SCL_BUS: J1.a28, R212.1
SDA: R211.2, U201.1 (ADDR), U201.9 (SDA), U206.8 (SDA)
SDA_BUS: J1.a26, R211.1
SPARE_A30: J1.a30
SPARE_A31: J1.a31
SPARE_A32: J1.a32
SPARE_C30: J1.c30
SPARE_C31: J1.c31
SPARE_C32: J1.c32
TIA1_OUT: C78.2, C94.2, R100.2, R213.1, TP401.1 (1_1), U30.1 (OUT)
TIA2_OUT: C79.2, C95.2, R101.2, R214.1, TP402.1 (1_1), U31.1 (OUT)
VREF_MID: C241.1, J1.a22, R140.1, R142.1, TP411.1 (1_1), U201.5 (AIN1), U201.7 (AIN3)

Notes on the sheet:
AFE CARD rev B - machine-extracted v3 PhotoDiodes/OPA859 TIAs/AD831 PhaseRef (BOTH channels) + universal bus interface.
U201 ADS1115 digitizes PD DC levels (RC taps off TIA outputs); pin numbers per TI datasheet (MSOP-10).
LO in (front SMA)
CARD ADDRESS is hard-strapped: U201 ADDR (pin 1) ties to SDA, so the ADS1115 answers at 0x4A. No jumper to mis-set.
LO1/LO2 arrive via front-panel SMA (J204 = LO1, J205 = LO2) per backplane rule - the c20 spare bus pin is fallback only.
Test points
BUS INTERFACE
Wiring is by net label at every pin (no graphic wires yet). Original v3 refdes kept for cross-reference.
DAC 0..2.5V moves ERRn_BUF DC over 1.98..2.97V (15uV/LSB). Powers up at midscale (RSTSEL=VLOGIC) = 2.48V, so an unwritten DAC is safe.
AGND from v3 mapped to single GND (star at DIN). Second LT3042 (+5.5V) was netlist-excluded in v3 - not carried over.
FGA01FC photodiodes (PD1/PD2) mount ON the front panel; only their three leads reach the board (Optical:PD_TO46_FGA01FC_3pin, 3 holes on a 2.5mm circle). Pin 1=K, 2=CASE, 3=A. Supplied with the optics - not on the BOM. The ANODE must sit millimetres from the TIA input: it is the compensated summing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
ERR out: ERRn_FILT -> U202/U203 OPA192 inverting x4.99 referenced to VBn -> 47R series -> ERRn_BUS. Zero error = VREF_MID (2.5V).
ERR OFFSET NULL is automatic - no trimpot. U206 AD5696R (0x0E) VOUTA/VOUTB inject via R146/R147 100k into VB1/VB2.
0x48/0x49 belong to the CH1/CH2 ADS1115s, so the AFE uses ADDR->SDA (ADS1115 ds). Backplane GA pins a20/c18/c19 (GA*_BP) intentionally unused.

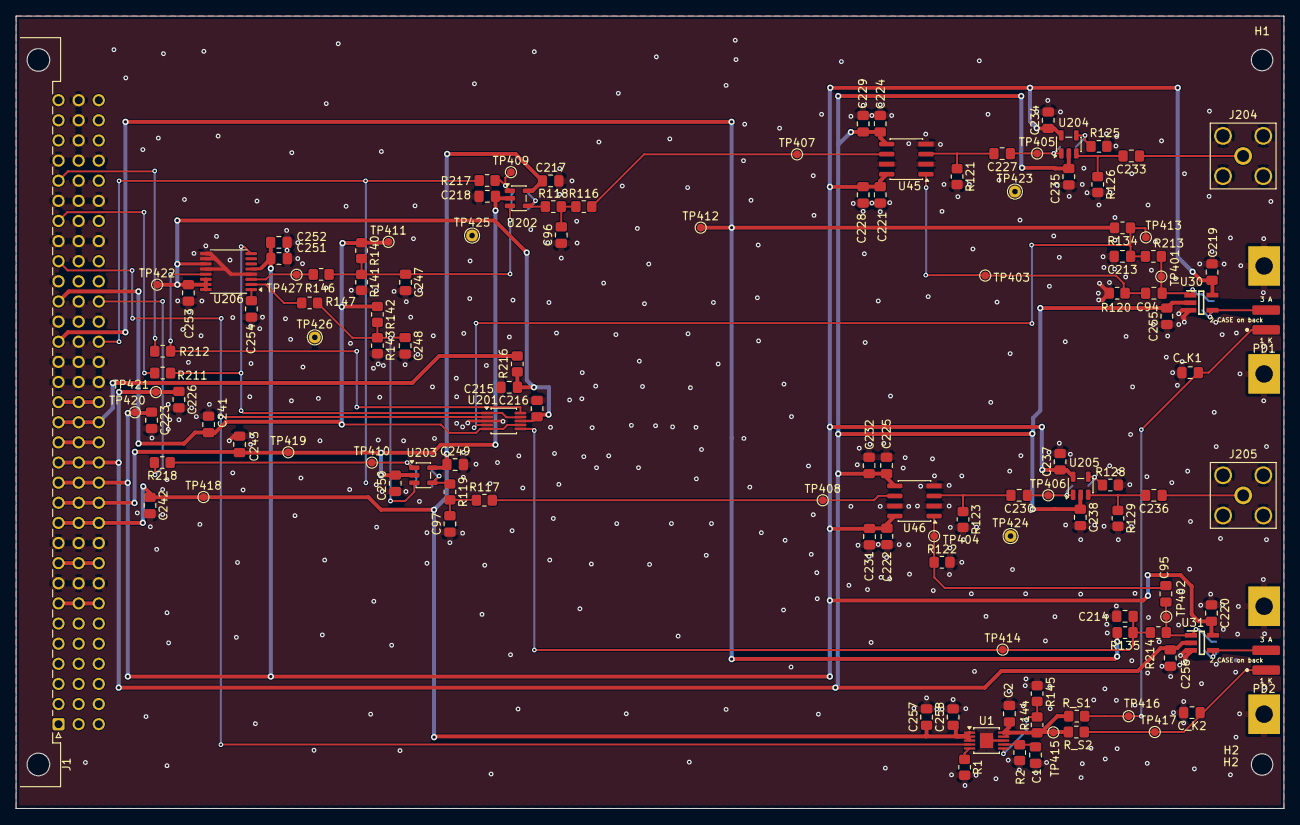
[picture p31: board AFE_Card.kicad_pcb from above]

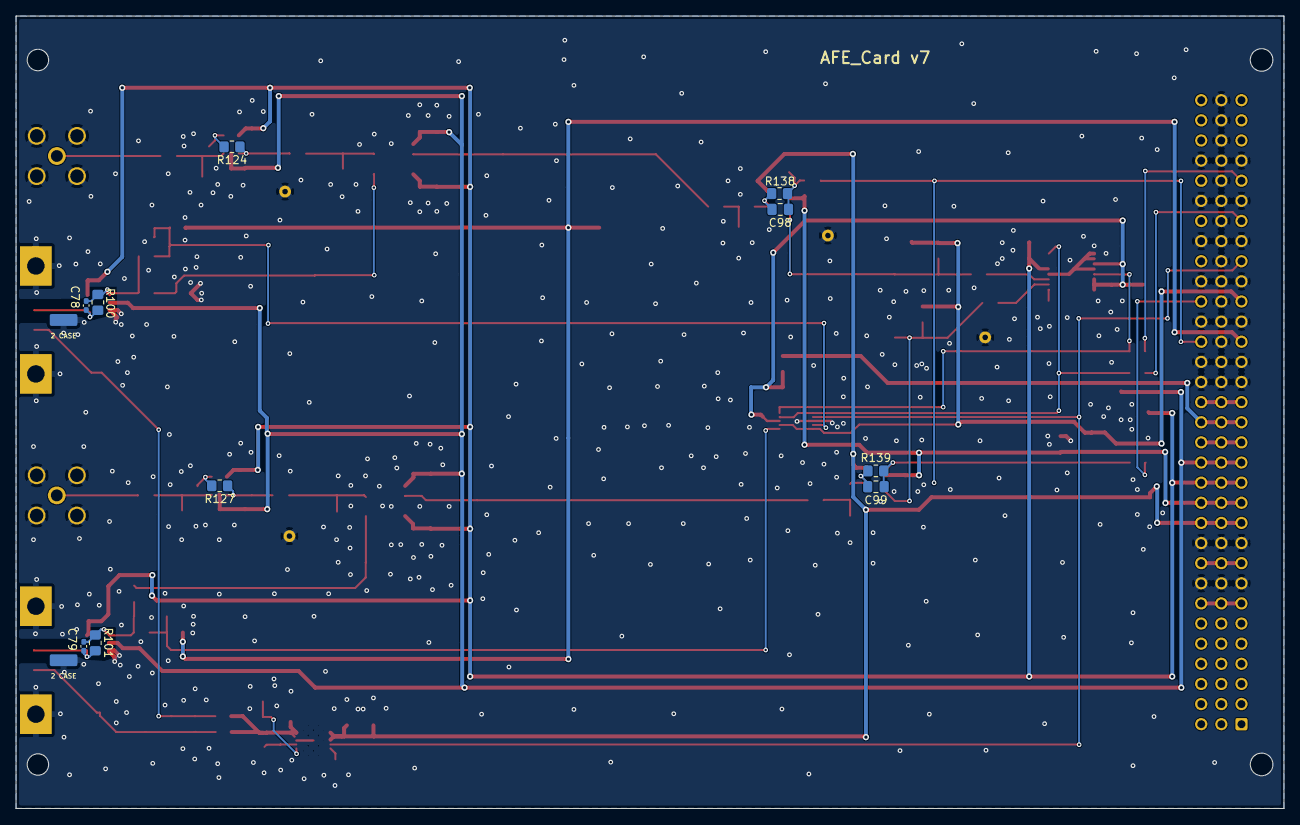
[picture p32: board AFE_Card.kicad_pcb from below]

Board: 2 copper layers, 160.0 x 100.0 mm, 137 parts (10 on the bottom side), 57 nets.

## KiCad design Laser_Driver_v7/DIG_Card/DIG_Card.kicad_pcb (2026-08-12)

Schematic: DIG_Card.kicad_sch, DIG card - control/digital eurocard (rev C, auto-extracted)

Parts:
A1: TEENSY_4.1; TEENSY_LONG_EXT
C80, C82, C84, C85: 100n; C_0805_2012Metric_Pad1.18x1.45mm_HandSolder
C81, C86: 100nF; C_0805_2012Metric_Pad1.18x1.45mm_HandSolder
C83, C87: 10n; C_0805_2012Metric_Pad1.18x1.45mm_HandSolder
C88, C92: 0.1uF; C_0805_2012Metric_Pad1.18x1.45mm_HandSolder
C89, C90, C91: 10nF; C_0805_2012Metric_Pad1.18x1.45mm_HandSolder
C301: 100nF U301 +15V; C_0805_2012Metric
C302: 100nF U301 -15V; C_0805_2012Metric
C303: 1n ERR1 ADC filter; C_0805_2012Metric
C304: 1n ERR2 ADC filter; C_0805_2012Metric
C305: 100nF U302 +15V; C_0805_2012Metric
C306: 100nF U302 -15V; C_0805_2012Metric
C307: 100nF U303 3V3; C_0805_2012Metric
C310: DNP MOD1 LPF; C_0805_2012Metric
C311: DNP MOD2 LPF; C_0805_2012Metric
C312: 100nF Y1 3V3_OSC; C_0805_2012Metric; MPN CL21B104KBCNNNC
C313: 1uF Y1 3V3_OSC; C_0805_2012Metric; MPN CC0805KKX7R8BB105
C314: 100nF U40 3V3; C_0805_2012Metric; MPN CL21B104KBCNNNC
C315: 100nF U41 3V3; C_0805_2012Metric; MPN CL21B104KBCNNNC
C316: 100nF U42 1V8; C_0805_2012Metric; MPN CL21B104KBCNNNC
C317: 100nF U42 3V3; C_0805_2012Metric; MPN CL21B104KBCNNNC
C318: 10uF U42 3V3; C_0805_2012Metric; MPN CC0805KKX5R7BB106
C319: 1uF U42 1V8_CLK; C_0805_2012Metric; MPN CC0805KKX7R8BB105
C320: 10nF U34 COMP; C_0805_2012Metric
C321: 10nF U39 COMP; C_0805_2012Metric
C322: 10uF +5V bulk; C_0805_2012Metric
C323: 10uF 3V3 bulk; C_0805_2012Metric
C324: 100nF 1V8 entry; C_0805_2012Metric
C325: 10uF 1V8 entry; C_0805_2012Metric
D24: BAV99; SOT-23
D301: BAT54S ERR1 ADC clamp; SOT-23
D302: BAT54S ERR2 ADC clamp; SOT-23
D303, D304, D305, D306, D307, D308, D309, D310, D311: BAT54WS VM fault OR; D_SOD-323
FB301: 600R@100MHz FB Y1; L_0805_2012Metric; MPN MPZ2012S601AT000
FB302: 600R@100MHz FB U42core; L_0805_2012Metric; MPN MPZ2012S601AT000
H1, H2: MountingHole; MountingHole_2.7mm
J2: 10MHz Ref SMA; SMA_BAT_Wireless_BWSMA-KWE-Z001
J301: DIN41612_03x32_C_Split; DIN41612_C_3x32_Male_Horizontal_THT
J302: LO1 out SMA; SMA_BAT_Wireless_BWSMA-KWE-Z001
J302B1: LO2 out SMA; SMA_BAT_Wireless_BWSMA-KWE-Z001
R104: 49R9 10MHz ref term; R_0805_2012Metric_Pad1.20x1.40mm_HandSolder
R105: 1M; R_0805_2012Metric_Pad1.20x1.40mm_HandSolder
R106: 27k; R_0805_2012Metric_Pad1.20x1.40mm_HandSolder
R107, R108, R111: 1k; R_0805_2012Metric_Pad1.20x1.40mm_HandSolder
R109: 100k; R_0805_2012Metric_Pad1.20x1.40mm_HandSolder
R110: 10M; R_0805_2012Metric_Pad1.20x1.40mm_HandSolder
R112, R113: 2.2k; R_0805_2012Metric_Pad1.20x1.40mm_HandSolder
R114: 100; R_0805_2012Metric_Pad1.20x1.40mm_HandSolder
R301, R302: 100R I2C series; R_0805_2012Metric
R303: 3k3 ERR1 ADC series; R_0805_2012Metric
R304: 3k3 ERR2 ADC series; R_0805_2012Metric
R305: 10k FAULT_n pullup; R_0805_2012Metric
R306: 47R MOD1 bus series; R_0805_2012Metric
R307: 47R MOD2 bus series; R_0805_2012Metric
R311: 33R CLK10M series; R_0805_2012Metric
R312: 49R9 LO1 series; R_0805_2012Metric
R313: 49R9 LO2 series; R_0805_2012Metric
R314: 0R MOD1 LPF (provision); R_0805_2012Metric
R315: 0R MOD2 LPF (provision); R_0805_2012Metric
R316: 33R MCLK2 series; R_0805_2012Metric
R317: 33R MCLK3 series; R_0805_2012Metric
R318: 33R MCLK1 series; R_0805_2012Metric
TP301: N_U41_B1; TestPoint_Pad_D1.0mm
TP302: N_U41_A; TestPoint_Pad_D1.0mm
TP303: CLK10M_BUF; TestPoint_Pad_D1.0mm
TP304: MCLK1; TestPoint_Pad_D1.0mm
TP305: MCLK2; TestPoint_Pad_D1.0mm
TP306: 3V3_OSC; TestPoint_Pad_D1.0mm
TP307: 1V8_CLK; TestPoint_Pad_D1.0mm
TP308: 3V3; TestPoint_Pad_D1.0mm
TP309: +5V; TestPoint_Pad_D1.0mm
TP310: 1V8; TestPoint_Pad_D1.0mm
TP311: 5Vref; TestPoint_Pad_D1.0mm
TP312: VREF_MID; TestPoint_Pad_D1.0mm
TP313: VHI; TestPoint_Pad_D1.0mm
TP314: VLO; TestPoint_Pad_D1.0mm
TP315, TP316, TP317, TP318, TP319, TP320: GND; TestPoint_THTPad_D1.5mm_Drill0.7mm
U34, U39: AD9833xRM; MSOP-10_3x3mm_P0.5mm
U35, U38: AD9833xRM (ref); MSOP-10_3x3mm_P0.5mm
U40: LMV7219M5; SOT-23-5
U41: SN74LVC1G3157DBVR; SOT-23-6_Handsoldering
U42: CDCE913PWG4; SOP65P640X120-14N
U44: CR2013-MI2120
U301: OPA192IDBVR MOD1 buffer; SOT-23-5
U302: OPA192IDBVR MOD2 buffer; SOT-23-5
U303: 74LVC1G125 CLK10M bus buffer; SOT-23-5
VM_C75, VM_C76, VM_C77, VM_C78, VM_C79, VM_C80, VM_C90: 100nF; C_0805_2012Metric_Pad1.18x1.45mm_HandSolder
VM_C81, VM_C82, VM_C83, VM_C84, VM_C85, VM_C86, VM_C87, VM_C88, VM_C89: 10nF; C_0805_2012Metric_Pad1.18x1.45mm_HandSolder
VM_D16: +15V_OK; LED_0805_2012Metric_Pad1.15x1.40mm_HandSolder
VM_D17: -15V_OK; LED_0805_2012Metric_Pad1.15x1.40mm_HandSolder
VM_D18: +5V_OK; LED_0805_2012Metric_Pad1.15x1.40mm_HandSolder
VM_D19: -5V_OK; LED_0805_2012Metric_Pad1.15x1.40mm_HandSolder
VM_D20: +6V_OK; LED_0805_2012Metric_Pad1.15x1.40mm_HandSolder
VM_D21: -6V_OK; LED_0805_2012Metric_Pad1.15x1.40mm_HandSolder
VM_D22: +5VLaser_OK; LED_0805_2012Metric_Pad1.15x1.40mm_HandSolder
VM_D23: 3V3_OK; LED_0805_2012Metric_Pad1.15x1.40mm_HandSolder
VM_D24: 1V8_OK; LED_0805_2012Metric_Pad1.15x1.40mm_HandSolder
VM_Q11, VM_Q12, VM_Q13, VM_Q14, VM_Q15, VM_Q16, VM_Q17, VM_Q18, VM_Q19: MMBT3904; SOT-23
VM_R50: 29.4k; R_0805_2012Metric_Pad1.20x1.40mm_HandSolder
VM_R51: 1k; R_0805_2012Metric_Pad1.20x1.40mm_HandSolder
VM_R52: 9.53k; R_0805_2012Metric_Pad1.20x1.40mm_HandSolder
VM_R53: 110k; R_0805_2012Metric_Pad1.20x1.40mm_HandSolder
VM_R54, VM_R55, VM_R58, VM_R60, VM_R62, VM_R63, VM_R67, VM_R69, VM_R70, VM_R73, VM_R75, VM_R76, VM_R79, VM_R80, VM_R81, VM_R82, VM_R84, VM_R85, VM_R86, VM_R87: 10k; R_0805_2012Metric_Pad1.20x1.40mm_HandSolder
VM_R56, VM_R66, VM_R72: 100; R_0805_2012Metric_Pad1.20x1.40mm_HandSolder
VM_R59: 120k; R_0805_2012Metric_Pad1.20x1.40mm_HandSolder
VM_R61: 40.2k; R_0805_2012Metric_Pad1.20x1.40mm_HandSolder
VM_R64: 47.5k; R_0805_2012Metric_Pad1.20x1.40mm_HandSolder
VM_R65, VM_R77: 30.1k; R_0805_2012Metric_Pad1.20x1.40mm_HandSolder
VM_R71: 38.3k; R_0805_2012Metric_Pad1.20x1.40mm_HandSolder
VM_R78: 16.5k; R_0805_2012Metric_Pad1.20x1.40mm_HandSolder
VM_R83: 4.42k; R_0805_2012Metric_Pad1.20x1.40mm_HandSolder
VM_R88, VM_R89, VM_R90, VM_R91, VM_R92, VM_R93, VM_R94, VM_R95, VM_R96: 1.3k; R_0805_2012Metric_Pad1.20x1.40mm_HandSolder
VM_R97, VM_R98, VM_R99, VM_R100, VM_R101, VM_R102, VM_R103, VM_R104, VM_R105: 4.7k; R_0805_2012Metric_Pad1.20x1.40mm_HandSolder
VM_U22: MCP6002-xSN; SOIC-8_3.9x4.9mm_P1.27mm
VM_U23, VM_U25, VM_U26, VM_U27, VM_U28: LM339B; SOIC-14_3.9x8.7mm_P1.27mm
VM_U24: MCP6004; SOIC-14_3.9x8.7mm_P1.27mm
Y1: ASE-10.000MHZ-LC-T; XTAL_ASE-10.000MHZ-LC-T

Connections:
1V8: C324.1, C325.1, FB302.2, J301.a17, J301.b17, J301.c17, R111.1, TP310.1 (1_1), VM_C81.2, VM_R83.1, VM_U28.9 (+), VM_U28.11 (+)
1V8_CLK: C316.1, C319.1, FB302.1, TP307.1 (1_1), U42.3 (VDD)
3.3V: A1.3V3 (3.3V), A1.3V3@2 (3.3V), A1.3V3@3 (3.3V)
3V3: C80.2, C84.2, C88.2, C92.2, C307.1, C314.1, C315.1, C317.1, C318.1, C323.1, D301.2 (K), D302.2 (K), FB301.1, J301.a16, J301.b16, J301.c16, R105.1, R112.2, R113.2, R114.2, R305.1, TP308.1 (1_1), U34.2 (VDD), U35.2 (VDD), U38.2 (VDD), U39.2 (VDD), U40.5 (V+), U41.5 (VCC), U42.6 (VDDOUT), U42.7 (VDDOUT), U44.1 (VCC), U303.5 (VCC), VM_R78.1
3V3_OSC: C312.1, C313.1, FB301.2, TP306.1 (1_1), Y1.1 (TRI-STATE(STBY)), Y1.4 (VDD)
5Vref: J301.a20, TP311.1 (1_1), VM_R50.1
+5V: A1.VIN, C322.1, J301.a13, J301.b13, J301.c13, TP309.1 (1_1), VM_C75.1, VM_C76.1, VM_C77.1, VM_C78.1, VM_C79.1, VM_C80.1, VM_C90.1, VM_R65.1, VM_R84.1, VM_R88.1, VM_R89.1, VM_R90.1, VM_R91.1, VM_R92.1, VM_R93.1, VM_R94.1, VM_R95.1, VM_R96.1, VM_R97.2, VM_R98.2, VM_R99.2, VM_R100.2, VM_R101.2, VM_R102.2, VM_R103.2, VM_R104.2, VM_R105.2, VM_U22.8 (V+), VM_U23.3 (V+), VM_U24.4 (V+), VM_U25.3 (V+), VM_U26.3 (V+), VM_U27.3 (V+), VM_U28.3 (V+)
+5V_LASER: J301.a15, J301.b15, J301.c15, VM_R77.1
+6V_TEC: J301.a1, J301.a2, J301.b1, J301.b2, J301.c1, J301.c2, VM_R71.1
+15V: C301.1, C305.1, J301.a11, J301.b11, J301.c11, U301.5 (V+), U302.5 (V+), VM_R53.1
+18V: J301.a7, J301.b7, J301.c7
-5V: J301.a14, J301.b14, J301.c14, VM_R61.1
-6V_TEC: J301.a5, J301.a6, J301.b5, J301.b6, J301.c5, J301.c6, VM_R64.1
-15V: C302.1, C306.1, J301.a12, J301.b12, J301.c12, U301.2 (V-), U302.2 (V-), VM_R59.1
-18V: J301.a9, J301.b9, J301.c9
/CLK10M_BUF: R311.1, TP303.1 (1_1), U303.4 (Y)
/DDS1_FSYNC: A1.D2, U34.8 (~FSYNC)
/DDS2_FSYNC: A1.D3, U39.8 (~FSYNC)
/DDS3_FSYNC: A1.D6, U35.8 (~FSYNC)
/DDS4_FSYNC: A1.D8, U38.8 (~FSYNC)
/ERR1_ADC: A1.D24 (A10), C303.1, D301.3 (COM), R303.2
/ERR2_ADC: A1.D25 (A11), C304.1, D302.3 (COM), R304.2
/LO1_OUT: J302.1 (In), R312.2
/LO2_OUT: J302B1.1 (In), R313.2
/MCLK1: R318.2, TP304.1 (1_1), U34.5 (MCLK), U35.5 (MCLK)
/MCLK1_S: R318.1, U42.11 (Y1)
/MCLK2: R316.2, TP305.1 (1_1), U38.5 (MCLK), U39.5 (MCLK)
/MCLK2_S: R316.1, U42.9 (Y2)
/MCLK3: A1.D9, R317.2
/MCLK3_S: R317.1, U42.8 (Y3)
/MOD1_BUF: R306.1, U301.1 (OUT), U301.4 (IN-)
/MOD1_IN: C310.1, R314.2, U301.3 (IN+)
/MOD2_BUF: R307.1, U302.1 (OUT), U302.4 (IN-)
/MOD2_IN: C311.1, R315.2, U302.3 (IN+)
/MOSI_3V3: A1.D11 ((SDO)D11), U34.6 (SDATA), U35.6 (SDATA), U38.6 (SDATA), U39.6 (SDATA)
/N_C89_Pad2: C89.2, R107.1
/N_C90_Pad2: C90.2, R108.1
/N_D24_A: C91.2, D24.3 (K), R109.1, R110.1, U40.3 (+)
/N_D24_K_Pad1: D24.1 (K), R108.2
/N_J2A_In1: C89.1, C90.1, J2.1 (In), R104.2
/N_U34_CAP/2_5V: C81.2, U34.3 (CAP/2.5V)
/N_U34_COMP: C320.1, U34.1 (COMP)
/N_U35_CAP/2_5V: C82.2, U35.3 (CAP/2.5V)
/N_U35_COMP: C83.1, U35.1 (COMP)
/N_U38_CAP/2_5V: C85.2, U38.3 (CAP/2.5V)
/N_U38_COMP: C87.1, U38.1 (COMP)
/N_U39_CAP/2_5V: C86.2, U39.3 (CAP/2.5V)
/N_U39_COMP: C321.1, U39.1 (COMP)
/N_U40__: R105.2, R106.1, U40.4 (-)
/N_U41_A: TP302.1 (1_1), U41.4 (A), U42.1 (XIN/CLK), U303.2 (A)
/N_U41_B1: TP301.1 (1_1), U41.3 (B1), Y1.3 (OUTPUT)
/N_U41_B2: R107.2, U41.1 (B2)
/N_U41_S: R110.2, U40.1, U41.6 (S)
/N_U42_S0: R111.2, U42.2 (S0)
/N_U44_D/~C: A1.D29, U44.5 (D/~C)
/N_U44_RESET: A1.D30, U44.4 (RESET)
/N_U44_~CS: A1.D28, U44.3 (~CS)
/OLD_AD5064_CLR: A1.D7
/OLD_CS_3V3: A1.D10 ((CS)D10)
/OLD_HBridgeFault2: A1.D32
/OLD_LAS2_IMON: A1.D22 (A8)
/OLD_LOCK1_EN: A1.D33
/OLD_LOCK2_EN: A1.D34
/OLD_MPD1_MON: A1.D17 (A3)
/OLD_MPD2_MON: A1.D23 (A9)
/OLD_NTC2_A: A1.D20 (A6)
/OLD_NTC_A14: A1.D38 (A14)
/OLD_TEC2_IMON: A1.D21 (A7)
/SCK_3V3: A1.D13 ((CLK)D13), U34.7 (SCLK), U35.7 (SCLK), U38.7 (SCLK), U39.7 (SCLK)
/TFT_MOSI: A1.D26 (A12), U44.6 (MOSI)
/TFT_SCK: A1.D27 (A13), U44.7 (SCK)
/VHI_Buf: TP313.1 (1_1), VM_U22.1, VM_U22.2 (-), VM_U23.5 (+), VM_U23.11 (+), VM_U25.5 (+), VM_U25.11 (+), VM_U26.5 (+), VM_U26.11 (+), VM_U27.5 (+), VM_U27.11 (+), VM_U28.5 (+)
/VLO_Buf: TP314.1 (1_1), VM_U22.6 (-), VM_U22.7, VM_U23.6 (-), VM_U23.8 (-), VM_U25.6 (-), VM_U25.8 (-), VM_U26.6 (-), VM_U26.8 (-), VM_U27.6 (-), VM_U27.8 (-), VM_U28.6 (-)
/VM_N_D16_A: VM_D16.2 (A), VM_R96.2
/VM_N_D16_K: VM_D16.1 (K), VM_Q11.3 (C)
/VM_N_D17_A: VM_D17.2 (A), VM_R95.2
/VM_N_D17_K: VM_D17.1 (K), VM_Q12.3 (C)
/VM_N_D18_A: VM_D18.2 (A), VM_R94.2
/VM_N_D18_K: VM_D18.1 (K), VM_Q13.3 (C)
/VM_N_D19_A: VM_D19.2 (A), VM_R93.2
/VM_N_D19_K: VM_D19.1 (K), VM_Q14.3 (C)
/VM_N_D20_A: VM_D20.2 (A), VM_R92.2
/VM_N_D20_K: VM_D20.1 (K), VM_Q15.3 (C)
/VM_N_D21_A: VM_D21.2 (A), VM_R91.2
/VM_N_D22_A: VM_D22.2 (A), VM_R88.2
/VM_N_D22_K: VM_D22.1 (K), VM_Q17.3 (C)
/VM_N_D23_K: VM_D23.1 (K), VM_Q18.3 (C)
/VM_N_D24_A: VM_D24.2 (A), VM_R90.2
/VM_N_D24_K: VM_D24.1 (K), VM_Q19.3 (C)
/VM_N_Q11_B: VM_Q11.1 (B), VM_R55.2
/VM_N_Q12_B: VM_Q12.1 (B), VM_R58.2
/VM_N_Q13_B: VM_Q13.1 (B), VM_R69.2
/VM_N_Q14_B: VM_Q14.1 (B), VM_R70.2
/VM_N_Q15_B: VM_Q15.1 (B), VM_R75.2
/VM_N_Q16_B: VM_Q16.1 (B), VM_R76.2
/VM_N_Q17_B: VM_Q17.1 (B), VM_R81.2
/VM_N_Q18_B: VM_Q18.1 (B), VM_R82.2
/VM_N_Q19_B: VM_Q19.1 (B), VM_R87.2
/VM_N_R55_Pad1: D303.1 (K), VM_R55.1, VM_R97.1, VM_U23.1, VM_U23.2
/VM_N_R56_Pad1: VM_R56.1, VM_R60.2, VM_U24.1
/VM_N_R58_Pad1: D304.1 (K), VM_R58.1, VM_R98.1, VM_U23.13, VM_U23.14
/VM_N_R62_Pad2: VM_R62.2, VM_R66.1, VM_U24.7
/VM_N_R63_Pad2: VM_R63.1, VM_R72.1, VM_U24.8
/VM_N_R69_Pad1: D305.1 (K), VM_R69.1, VM_R99.1, VM_U25.1, VM_U25.2
/VM_N_R100_Pad1: D306.1 (K), VM_R70.1, VM_R100.1, VM_U25.13, VM_U25.14
/VM_N_R101_Pad1: D307.1 (K), VM_R75.1, VM_R101.1, VM_U26.1, VM_U26.2
/VM_N_R102_Pad1: D308.1 (K), VM_R76.1, VM_R102.1, VM_U26.13, VM_U26.14
/VM_N_R103_Pad1: D309.1 (K), VM_R87.1, VM_R103.1, VM_U28.1, VM_U28.2
/VM_N_R104_Pad1: D310.1 (K), VM_R82.1, VM_R104.1, VM_U27.13, VM_U27.14
/VM_N_R105_Pad1: D311.1 (K), VM_R81.1, VM_R105.1, VM_U27.1, VM_U27.2
/VM_N_U23A__: VM_C84.1, VM_R53.2, VM_R54.1, VM_U23.4 (-), VM_U23.7 (+)
/VM_N_U23C__: VM_C85.1, VM_R56.2, VM_U23.9 (+), VM_U23.10 (-)
/VM_N_U24A__: VM_R59.2, VM_R60.1, VM_U24.2 (-)
/VM_N_U24B__: VM_R61.2, VM_R62.1, VM_U24.6 (-)
/VM_N_U24C__: VM_R63.2, VM_R64.2, VM_U24.9 (-)
/VM_N_U24D_P: VM_R84.2, VM_R86.1, VM_U24.12 (+)
/VM_N_U24D__: VM_U24.13 (-), VM_U24.14
/VM_N_U25A__: VM_C86.1, VM_R65.2, VM_R67.1, VM_U25.4 (-), VM_U25.7 (+)
/VM_N_U25C__: VM_C87.1, VM_R66.2, VM_U25.9 (+), VM_U25.10 (-)
/VM_N_U26A__: VM_C88.1, VM_R71.2, VM_R73.1, VM_U26.4 (-), VM_U26.7 (+)
/VM_N_U26C__: VM_C89.1, VM_R72.2, VM_U26.9 (+), VM_U26.10 (-)
/VM_N_U27A__: VM_C83.1, VM_R77.2, VM_R79.1, VM_U27.4 (-), VM_U27.7 (+)
/VM_N_U27C__: VM_C82.1, VM_R78.2, VM_R80.1, VM_U27.9 (+), VM_U27.10 (-)
/VM_N_U28A__: VM_C81.1, VM_R83.2, VM_R85.1, VM_U28.4 (-), VM_U28.7 (+)
/_VoltageMonitor_VHI: VM_R50.2, VM_R51.1, VM_U22.3 (+)
/_VoltageMonitor_VLO: VM_R51.2, VM_R52.1, VM_U22.5 (+)
CLK10M_BUS: J301.c28, R311.2
ERR1_BUS: J301.c20, R303.1
ERR2_BUS: J301.c22, R304.1
FAULT_n: A1.D31, D303.2 (A), D304.2 (A), D305.2 (A), D306.2 (A), D307.2 (A), D308.2 (A), D309.2 (A), D310.2 (A), D311.2 (A), J301.a24, R305.2
GND: A1.AGND/GND (GND), A1.GND, A1.GND@2 (GND), C80.1, C81.1, C82.1, C83.2, C84.1, C85.1, C86.1, C87.2, C88.1, C91.1, C92.1, C301.2, C302.2, C303.2, C304.2, C305.2, C306.2, C307.2, C310.2, C311.2, C312.2, C313.2, C314.2, C315.2, C316.2, C317.2, C318.2, C319.2, C320.2, C321.2, C322.2, C323.2, C324.2, C325.2, D301.1 (A), D302.1 (A), J2.2 (Ext), J301.a8, J301.a10, J301.a18, J301.a19, J301.a21, J301.a23, J301.a25, J301.a27, J301.a29, J301.b8, J301.b10, J301.b18, J301.b19, J301.b20, J301.b21, J301.b22, J301.b23, J301.b24, J301.b25, J301.b26, J301.b27, J301.b28, J301.b29, J301.b30, J301.b31, J301.b32, J301.c8, J301.c10, J301.c18, J301.c19, J301.c21, J301.c23, J301.c25, J301.c27, J301.c29, J302.2 (Ext), J302B1.2 (Ext), R104.1, R106.2, R109.2, TP315.1 (1_1), TP316.1 (1_1), TP317.1 (1_1), TP318.1 (1_1), TP319.1 (1_1), TP320.1 (1_1), U34.4 (DGND), U34.9 (AGND), U35.4 (DGND), U35.9 (AGND), U38.4 (DGND), U38.9 (AGND), U39.4 (DGND), U39.9 (AGND), U40.2 (V-), U41.2 (GND), U42.5 (GND), U42.10 (GND), U44.2 (GND), U303.1 (~OE), U303.3 (GND), VM_C75.2, VM_C76.2, VM_C77.2, VM_C78.2, VM_C79.2, VM_C80.2, VM_C82.2, VM_C83.2, VM_C84.2, VM_C85.2, VM_C86.2, VM_C87.2, VM_C88.2, VM_C89.2, VM_C90.2, VM_Q11.2 (E), VM_Q12.2 (E), VM_Q13.2 (E), VM_Q14.2 (E), VM_Q15.2 (E), VM_Q16.2 (E), VM_Q17.2 (E), VM_Q18.2 (E), VM_Q19.2 (E), VM_R52.2, VM_R54.2, VM_R67.2, VM_R73.2, VM_R79.2, VM_R80.2, VM_R85.2, VM_R86.2, VM_U22.4 (V-), VM_U23.12 (V-), VM_U24.3 (+), VM_U24.5 (+), VM_U24.10 (+), VM_U24.11 (V-), VM_U25.12 (V-), VM_U26.12 (V-), VM_U27.12 (V-), VM_U28.8 (-), VM_U28.10 (-), VM_U28.12 (V-), Y1.2 (GND/CASE)
LO1_REF: R312.1, U35.10 (VOUT)
LO2_REF: R313.1, U38.10 (VOUT)
MOD1_BUS: J301.c24, R306.2
MOD1_FILT: R314.1, U34.10 (VOUT)
MOD2_BUS: J301.c26, R307.2
MOD2_FILT: R315.1, U39.10 (VOUT)
unnamed: R114.1, U44.8 (LED)
unnamed: VM_D21.1 (K), VM_Q16.3 (C)
unnamed: VM_D23.2 (A), VM_R89.2
PGND_TEC: J301.a3, J301.a4, J301.b3, J301.b4, J301.c3, J301.c4
SCL: A1.D19 (A5), R113.1, R302.2, U42.12 (S2/SCL)
SCL_BUS: J301.a28, R302.1
SDA: A1.D18 (A4), R112.1, R301.2, U42.13 (S1/SDA)
SDA_BUS: J301.a26, R301.1
SPARE_A30: J301.a30
SPARE_A31: J301.a31
SPARE_A32: J301.a32
SPARE_C30: J301.c30
SPARE_C31: J301.c31
SPARE_C32: J301.c32
VREF_MID: J301.a22, TP312.1 (1_1)

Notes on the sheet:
I2C: Teensy = master; MCU_SDA/SCL merged onto card net SDA/SCL (also serves CDCE913); bus pullups = existing R112/R113 4.7k (Clock sheet) - the ONLY pullups on the whole backplane bus.
VoltageMonitor windows +/-15V, +/-5V, +/-6V_TEC, +5V_LASER, 3V3, 1V8. +/-18V blades (P5-P8) pass through UNMONITORED.
OLD_* nets = Teensy pins freed by the I2C migration (monitors, LOCK_EN, faults, CS/CLR, PowerNTC) - reassign in firmware pass.
I2C pullups R112/R113 4.7k -> 2.2k (sole pullups for 8-slot bus); VM fault nodes diode-ORed onto FAULT_n (D303-D311,
Wiring by net label at every pin (no graphic wires). AD5064 U37 REMOVED - setpoints now on-card I2C DACs (CH cards).
R110 = ext-ref auto-select hysteresis (hold = 3V3*R109 / (R110+R109), R109=100k; U40 trip = +86.8mV): 10M (fitted): hold ~33mV < trip -> releases when ext ref unplugged 1M: hold ~300mV > trip -> latches to ext until power-cycle 0R: node tied to U40 OUT -> hard latch, defeats auto-detect
DDS MOD-LO GEN (v3, no AD5064)
is this clock buffer needed?
LO SMAs get 49R9 back-termination (R312/R313); MOD LPF provision R314/R315 0R + C310/C311 DNP ahead of buffers.
LO1/LO2 out via J302 front SMAs (coax to AFE card). 10MHz ref on Clock J2 as in v3.
BAT54WS, node LOW = rail fault pulls bus); 10MHz mux output buffered to bus c20 (U303 74LVC1G125 + R311 33R);
ASSEMBLY: CUT the VUSB-VIN pad on the Teensy 4.1 - otherwise plugging USB drives 5V onto the crate +5V rail.
CARD ADDRESS via on-card jumpers JP301-JP303 (10k pullups R308-R310 to 3V3): fit jumper = 0, open = 1.
Backplane GA pins a20/c18/c19 (GA*_BP) intentionally unused - address lives on the card (scheme change 2026-07-16).
GA0/GA1/GA2 = Teensy pins 14/15/16 (freed A0/A1/A2); FAULT_n = Teensy pin 31 (was HBridgeFault1) - matches firmware config.h.
TEENSY + TFT (v3)
ERR1/ERR2_BUS -> 3k3/1n RC + BAT54S clamp -> Teensy ADC (ERRn_ADC). Restores v3 R118/C98 dropped in the port.
REV C cleanups: U36 74AHCT125 deleted (fed removed AD5064); R3/R4/C3 PowerNTC divider deleted (A1.D38 -> OLD_NTC_A14);
REV C (2026-07-19): U301/U302 now real SOT-23-5 OPA192 symbol (v3 LT1028_2 numbering matched no package);
Teensy VIN moved 3V3 -> +5V (a16); ERR bus conditioned: 3k3 (R303/R304) + 1n (C303/C304) + BAT54S clamps (D301/D302).
DIG CARD rev C - v3 Teensy/laser_control/Clock + VoltageMonitor (power board, refs VM_*) + universal bus IF.
MOD buses buffered: DDS out (MODn_FILT) -> U301/U302 OPA192 follower -> 47R -> MODn_BUS.
BUS INTERFACE (new)

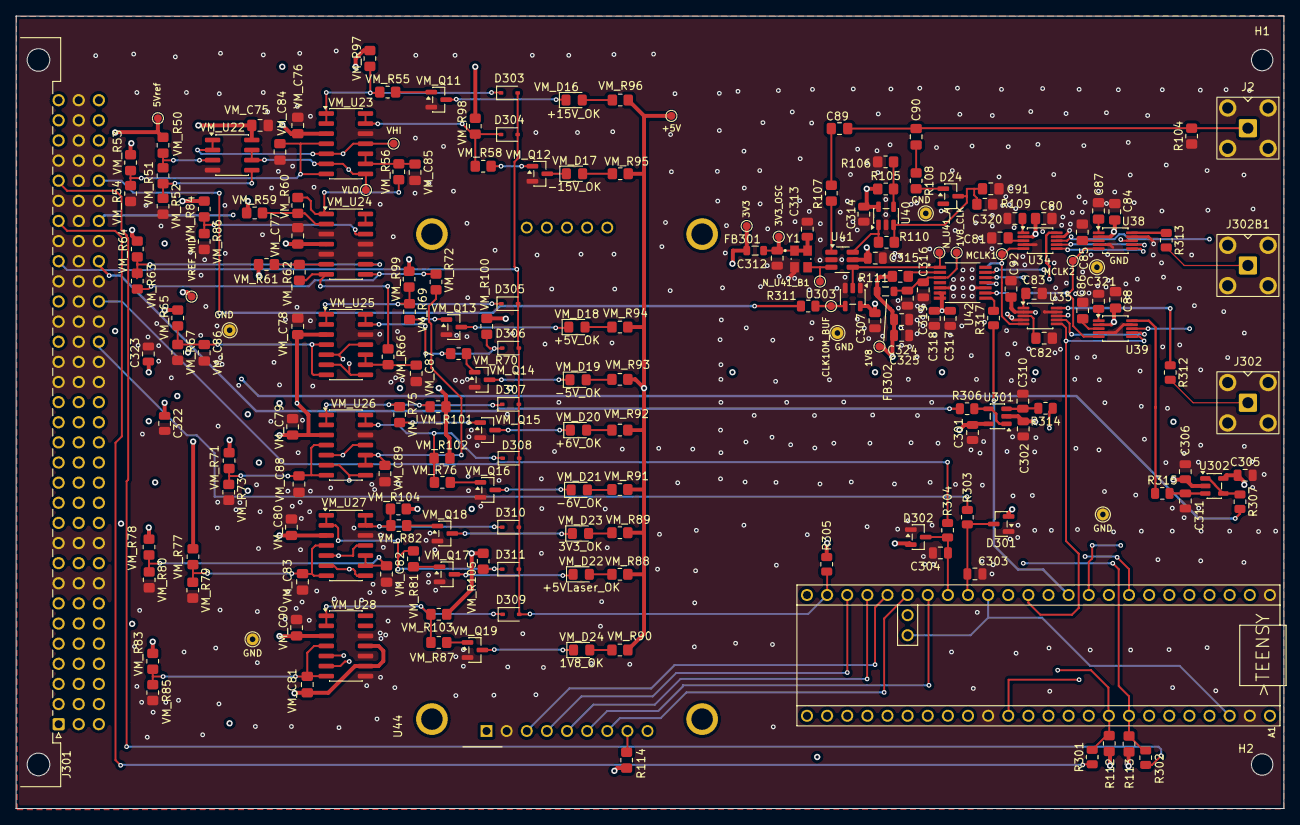
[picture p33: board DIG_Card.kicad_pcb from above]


Board: 6 copper layers, 160.0 x 100.0 mm, 209 parts (2 on the bottom side), 135 nets.

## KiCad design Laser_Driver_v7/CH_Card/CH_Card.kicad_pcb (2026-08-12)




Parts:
C65: 100nF; C_0805_2012Metric_Pad1.18x1.45mm_HandSolder
C66: 100n; C_0805_2012Metric_Pad1.18x1.45mm_HandSolder
C68: 100pF NP0; C_0805_2012Metric_Pad1.18x1.45mm_HandSolder
C70: 10n C0G; C_0805_2012Metric_Pad1.18x1.45mm_HandSolder
C76: Ci 1n C0G; C_0805_2012Metric_Pad1.18x1.45mm_HandSolder
C113, C114: 1uF DAC filter; C_0805_2012Metric_Pad1.18x1.45mm_HandSolder
C115: 10uF I2C-3V3; C_0805_2012Metric_Pad1.18x1.45mm_HandSolder
C116: 100nF decouple; C_0805_2012Metric_Pad1.18x1.45mm_HandSolder
C117: 100nF decouple ADC; C_0805_2012Metric_Pad1.18x1.45mm_HandSolder
C118: 100nF decouple expander; C_0805_2012Metric_Pad1.18x1.45mm_HandSolder
C119, C120: 10nF ADC filter; C_0805_2012Metric_Pad1.18x1.45mm_HandSolder
C121: 10uF DAC VDD; C_0805_2012Metric_Pad1.18x1.45mm_HandSolder
C122: 100nF DAC VDD; C_0805_2012Metric_Pad1.18x1.45mm_HandSolder
C123: 100nF DAC VREF out; C_0805_2012Metric_Pad1.18x1.45mm_HandSolder
C130, C131, C133, C134, C135, C136, C137, C138, C139, C142, C167, C169, C173: 100nF +15V dec; C_0805_2012Metric_Pad1.18x1.45mm_HandSolder
C132, C140, C141, C143, C144, C145, C146, C147, C148, C149, C168, C170, C174: 100nF -15V dec; C_0805_2012Metric_Pad1.18x1.45mm_HandSolder
C150: 10uF +15V bulk; C_0805_2012Metric_Pad1.18x1.45mm_HandSolder
C151: 10uF -15V bulk; C_0805_2012Metric_Pad1.18x1.45mm_HandSolder
C152: 100nF 3V3 dec TIA; C_0805_2012Metric_Pad1.18x1.45mm_HandSolder
C153: 100nF 3V3 dec; C_0805_2012Metric_Pad1.18x1.45mm_HandSolder
C154: 10uF 3V3 bulk; C_0805_2012Metric_Pad1.18x1.45mm_HandSolder
C155, C156: 100nF +5V dec; C_0805_2012Metric_Pad1.18x1.45mm_HandSolder
C157: 10uF +5V_LASER bulk; C_0805_2012Metric_Pad1.18x1.45mm_HandSolder
C158: 100nF +5V_LASER dec; C_0805_2012Metric_Pad1.18x1.45mm_HandSolder
C159: 100uF +6V_TEC bulk; C_1210_3225Metric
C160: 10uF +6V_TEC; C_0805_2012Metric_Pad1.18x1.45mm_HandSolder
C161: 100nF +6V_TEC dec; C_0805_2012Metric_Pad1.18x1.45mm_HandSolder
C162: 100uF -6V_TEC bulk; C_1210_3225Metric
C163: 10uF -6V_TEC; C_0805_2012Metric_Pad1.18x1.45mm_HandSolder
C164: 100nF -6V_TEC dec; C_0805_2012Metric_Pad1.18x1.45mm_HandSolder
C165: 100nF 5Vref dec; C_0805_2012Metric_Pad1.18x1.45mm_HandSolder
C166: 100nF VREF_MID dec; C_0805_2012Metric_Pad1.18x1.45mm_HandSolder
C171: 100nF loop comp; C_0805_2012Metric_Pad1.18x1.45mm_HandSolder
C172: 100nF -5V dec; C_0805_2012Metric_Pad1.18x1.45mm_HandSolder
C175: 10nF CASE shield RF bypass (par R75); C_0805_2012Metric_Pad1.18x1.45mm_HandSolder
C176: 100nF U105 +5V dec; C_0805_2012Metric_Pad1.18x1.45mm_HandSolder
C177: 100nF U108 +5V dec; C_0805_2012Metric_Pad1.18x1.45mm_HandSolder
C_NTC1: 100nF ADC filter; C_0805_2012Metric_Pad1.18x1.45mm_HandSolder
C_f1: 2.2pF Cf; C_0402_1005Metric
C_f2: 2.2pF Cf TIA; C_0402_1005Metric
D16, D17, D20, D21: MMSZ4702 15V; D_SOD-123
D22: BAT46W rev prot; D_SOD-123
D23: BAT46W flag clamp; D_SOD-123
H1: MountingHole; MountingHole_2.7mm
HS1: 657-10ABPE (Q13)
HS2: 657-10ABPE (Q14)
HS3: 657-10ABPE (Q17)
HS4: 657-10ABPE (Q18)
J1: DIN41612_03x32_C_Split; DIN41612_C_3x32_Male_Horizontal_THT
JP101: GA0 addr jumper; PinHeader_1x02_P2.54mm_Vertical
J_BTF1: Butterfly daughter-card stacking header - Samtec 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; BTF_Card_Mezzanine_2x07_M3
L1: 10u (SRF>>20MHz); L_1812_4532Metric_Pad1.30x3.40mm_HandSolder
Q13, Q17: IRL540N; TO-220-3_Vertical_HS657-10ABPE
Q14, Q18: IRF9540N; TO-220-3_Vertical_HS657-10ABPE
Q19: DMN3404L; SOT-23
R41: 3.16k; R_0805_2012Metric_Pad1.20x1.40mm_HandSolder
R42, R55: 1k; R_0805_2012Metric_Pad1.20x1.40mm_HandSolder
R43, R45: 20k 0.1% TEC_scaler_bot; R_0805_2012Metric
R44: 4.99k 0.1% TEC_scaler_top; R_0805_2012Metric
R48: 10R; R_0805_2012Metric_Pad1.20x1.40mm_HandSolder
R49: 33k flag pulldown; R_0805_2012Metric_Pad1.20x1.40mm_HandSolder
R56, R57, R58, R59: 470R gate; R_0805_2012Metric_Pad1.20x1.40mm_HandSolder
R63, R65: 0.1R; R_2512_6332Metric
R66: 200k 0.1% scaler_top; R_0805_2012Metric
R67: 909R 0.1% scaler_bot; R_0805_2012Metric
R68, R76: 10mR link (was 47R - TEC path); R_2512_6332Metric
R69, R70, R75: 47R prot; R_0805_2012Metric_Pad1.20x1.40mm_HandSolder
R73, R74: 0R link (was 47R - laser path); R_0805_2012Metric_Pad1.20x1.40mm_HandSolder
R77: 2k (trim); R_0805_2012Metric_Pad1.20x1.40mm_HandSolder
R78: 100k; R_0805_2012Metric_Pad1.20x1.40mm_HandSolder
R79: 10k gate; R_0805_2012Metric_Pad1.20x1.40mm_HandSolder
R81: 0.25R 1W; R_2512_6332Metric
R86: 4R7 inrush limit; R_2512_6332Metric
R92: Ri 10k; R_0805_2012Metric_Pad1.20x1.40mm_HandSolder
R94: Rp 1k; R_0805_2012Metric_Pad1.20x1.40mm_HandSolder
R96: Rsum 7.5M; R_0805_2012Metric_Pad1.20x1.40mm_HandSolder
R98: 487R; R_0805_2012Metric_Pad1.20x1.40mm_HandSolder
R102: 8.06k; R_0805_2012Metric_Pad1.20x1.40mm_HandSolder
R111, R112: 100R I2C series; R_0805_2012Metric_Pad1.20x1.40mm_HandSolder
R113, R114: 100R DAC filter; R_0805_2012Metric_Pad1.20x1.40mm_HandSolder
R115: 10k RESET pullup; R_0805_2012Metric_Pad1.20x1.40mm_HandSolder
R116: 10R I2C-3V3 filter; R_0805_2012Metric_Pad1.20x1.40mm_HandSolder
R117: 2.00k VZERO trim (v3 R40); R_0805_2012Metric_Pad1.20x1.40mm_HandSolder
R118, R119: 4.99k ADC prot; R_0805_2012Metric_Pad1.20x1.40mm_HandSolder
R120: 10k LOCK_EN pulldown; R_0805_2012Metric_Pad1.20x1.40mm_HandSolder
R121: 10k IO3 pulldown; R_0805_2012Metric_Pad1.20x1.40mm_HandSolder
R122: 10k IO4 pulldown; R_0805_2012Metric_Pad1.20x1.40mm_HandSolder
R123: 10k IO5 pulldown; R_0805_2012Metric_Pad1.20x1.40mm_HandSolder
R124: 10k IO6 pulldown; R_0805_2012Metric_Pad1.20x1.40mm_HandSolder
R125: 10k IO7 pulldown; R_0805_2012Metric_Pad1.20x1.40mm_HandSolder
R126: 10R DAC-5V filter; R_0805_2012Metric_Pad1.20x1.40mm_HandSolder
R127: 10k GA0 pullup; R_0805_2012Metric_Pad1.20x1.40mm_HandSolder
R130: 10k 0.1% inv in; R_0805_2012Metric_Pad1.20x1.40mm_HandSolder
R131: 10k 0.1% inv fb; R_0805_2012Metric_Pad1.20x1.40mm_HandSolder
R132: 10R buf iso; R_0805_2012Metric_Pad1.20x1.40mm_HandSolder
R133: 10k 0.1% IMON fb; R_0805_2012Metric_Pad1.20x1.40mm_HandSolder
R134: 15M pedestal cancel; R_0805_2012Metric_Pad1.20x1.40mm_HandSolder
R_NTC1: 10k 0.1% NTC1 pullup; R_0805_2012Metric
R_bias1: 20k 0.1% PD bias; R_0805_2012Metric
R_f1: 10k 0.1% Rf; R_0805_2012Metric_Pad1.20x1.40mm_HandSolder
R_f2: 10k 0.1% Rf TIA; R_0805_2012Metric_Pad1.20x1.40mm_HandSolder
TP501: TEC_VZERO; TestPoint_Pad_D1.0mm
TP502: N_U19_OUT; TestPoint_Pad_D1.0mm
TP503: N_U19_INM; TestPoint_Pad_D1.0mm
TP504: N_U106_OUT; TestPoint_Pad_D1.0mm
TP505: N_U21__; TestPoint_Pad_D1.0mm
TP506: N_U107_OUT; TestPoint_Pad_D1.0mm
TP507: N_Q13_S; TestPoint_Pad_D1.0mm
TP508: N_Q17_S; TestPoint_Pad_D1.0mm
TP509: TEC_BTF_P; TestPoint_Pad_D1.0mm
TP510: TEC_BTF_N; TestPoint_Pad_D1.0mm
TP511: TEC_IMON; TestPoint_Pad_D1.0mm
TP512: VOUT_LAS; TestPoint_Pad_D1.0mm
TP513: N_U22_INP; TestPoint_Pad_D1.0mm
TP514: N_Q19_S; TestPoint_Pad_D1.0mm
TP515: LAS_IMON; TestPoint_Pad_D1.0mm
TP516: N_U24_OUT; TestPoint_Pad_D1.0mm
TP517: BTF_LASER; TestPoint_Pad_D1.0mm
TP518: MPD_MON; TestPoint_Pad_D1.0mm
TP519: NTC_A; TestPoint_Pad_D1.0mm
TP520: TEC_EN; TestPoint_Pad_D1.0mm
TP521: N_U21_Flag; TestPoint_Pad_D1.0mm
TP522: LOCK_EN; TestPoint_Pad_D1.0mm
TP523: VREF_MID; TestPoint_Pad_D1.0mm
TP524: 5Vref; TestPoint_Pad_D1.0mm
TP525: +5V_LASER; TestPoint_Pad_D1.0mm
TP526: VZERO_SET; TestPoint_Pad_D1.0mm
TP527, TP528, TP529, TP530: GND; TestPoint_THTPad_D1.5mm_Drill0.7mm
U17, U19, U22, U24, U106: OPA192IDBVR; SOT-23-5
U21, U107: OPA551U; SOIC-8_3.9x4.9mm_P1.27mm
U26, U104, U105, U108: ADG419BRM; MSOP-8_3x3mm_P0.65mm
U28, U32: INA828; SOIC-8_3.9x4.9mm_P1.27mm
U101: AD5696R; TSSOP-16_4.4x5mm_P0.65mm
U102: ADS1115; MSOP-10_3x3mm_P0.5mm
U103: PCA9538; TSSOP-16_4.4x5mm_P0.65mm
U_TIA1, U_TIA2: OPA380AIDR MPD; SOIC-8_3.9x4.9mm_P1.27mm

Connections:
1V8: J1.a17, J1.b17, J1.c17
3V3: C152.1, C153.1, C154.1, D23.1 (K), J1.a16, J1.b16, J1.c16, R116.2, R_NTC1.1, U_TIA1.7 (V+), U_TIA2.7 (V+)
3V3_DIG: C115.1, C116.1, C117.1, C118.1, R115.1, R116.1, R127.1, U101.10 (GAIN), U101.11 (VLOGIC), U101.15 (~RESET), U102.8 (VDD), U103.16 (VDD)
5Vref: C165.1, J1.a20, R41.1, TP524.1 (1_1)
+5V: C155.1, C156.1, C176.1, C177.1, J1.a13, J1.b13, J1.c13, R126.1, U26.5 (VL), U104.5 (VL), U105.5 (VL), U108.5 (VL)
+5V_LASER: C157.1, C158.1, J1.a15, J1.b15, J1.c15, R86.1, TP525.1 (1_1)
+6V_TEC: C159.1, C160.1, C161.1, D17.1 (K), D21.1 (K), J1.a1, J1.a2, J1.b1, J1.b2, J1.c1, J1.c2, Q13.2 (D), Q17.2 (D)
+15V: C130.1, C131.1, C133.1, C134.1, C135.1, C136.1, C137.1, C138.1, C139.1, C142.1, C150.1, C167.1, C169.1, C173.1, J1.a11, J1.b11, J1.c11, U17.5 (V+), U19.5 (V+), U21.7 (V+), U22.5 (V+), U24.5 (V+), U26.4 (V+), U28.8 (Vs+), U32.8 (Vs+), U104.4 (V+), U105.4 (V+), U106.5 (V+), U107.7 (V+), U108.4 (V+)
+18V: J1.a7, J1.b7, J1.c7
-5V: C172.1, J1.a14, J1.b14, J1.c14, R134.2
-6V_TEC: C162.1, C163.1, C164.1, D16.2 (A), D20.2 (A), J1.a5, J1.a6, J1.b5, J1.b6, J1.c5, J1.c6, Q14.2 (D), Q18.2 (D)
-15V: C132.1, C140.1, C141.1, C143.1, C144.1, C145.1, C146.1, C147.1, C148.1, C149.1, C151.1, C168.1, C170.1, C174.1, J1.a12, J1.b12, J1.c12, U17.2 (V-), U19.2 (V-), U21.1 (V-), U21.4 (V-), U21.5 (V-), U22.2 (V-), U24.2 (V-), U26.7 (V-), U28.5 (Vs-), U32.5 (Vs-), U104.7 (V-), U105.7 (V-), U106.2 (V-), U107.1 (V-), U107.4 (V-), U107.5 (V-), U108.7 (V-)
-18V: J1.a9, J1.b9, J1.c9
/5V_DAC: C121.1, C122.1, R126.2, U101.5 (VDD)
/BTF_LASER: C70.2, D22.1 (K), L1.2, R73.2, TP517.1 (1_1)
/BTF_LASER_K: D22.2 (A), Q19.3 (D), R74.2
/DAC_LAS_RAW: R113.1, U101.3 (VOUTA)
/DAC_TEC_RAW: R114.1, U101.2 (VOUTB)
/DAC_VZERO_TRIM: R117.1, U101.7 (VOUTD)
/LAS_IMON_F: C119.1, R118.2, U102.4 (AIN0)
/MPD_K: J_BTF1.5 (NTC_GND), R_bias1.1, U_TIA1.3 (IN+)
/N_C66_~_Pad2: C66.2, R77.1
/N_C70_~_Pad1: C70.1, R77.2, R78.2
/N_C76_~_Pad1: C76.1, R94.1, U26.2
/N_D16_K: D16.1 (K), Q14.1 (G), R58.2
/N_D17_A: D17.2 (A), Q13.1 (G), R57.2
/N_D20_K: D20.1 (K), Q18.1 (G), R59.2
/N_D21_A: D21.2 (A), Q17.1 (G), R56.2
/N_IO4: R122.1, U103.9 (IO4)
/N_IO5: R123.1, U103.10 (IO5)
/N_IO6: R124.1, U103.11 (IO6)
/N_IO7: R125.1, U103.12 (IO7)
/N_J_BTF1_CHIP_: J_BTF1.12 (NC), R74.1
/N_J_BTF1_GND: C175.1, J_BTF1.3 (NC), J_BTF1.4 (NC), J_BTF1.9 (NC), J_BTF1.11 (CHIP-), R75.1
/N_J_BTF1_LD_A: J_BTF1.10 (CHIP+), R73.1
/N_J_BTF1_NTC_A: J_BTF1.7 (NC), R69.2
/N_J_BTF1_NTC_GND: J_BTF1.8 (NC), R70.2
/N_J_BTF1_TECP: J_BTF1.1 (TEC+), J_BTF1.2 (NTC_A), R68.2
/N_J_BTF1_TEC_: J_BTF1.13 (GND), J_BTF1.14 (TEC-), R76.1
/N_L1_Pad1: L1.1, R86.2
/N_Q13_S: Q13.3 (S), Q14.3 (S), R63.1, TP507.1 (1_1)
/N_Q17_S: Q17.3 (S), Q18.3 (S), R65.2, TP508.1 (1_1), U32.4 (+)
/N_Q19_G: Q19.1 (G), R79.2
/N_Q19_S: C68.1, Q19.2 (S), R81.1, TP514.1 (1_1), U22.4 (IN-), U28.4 (+)
/N_RST9538: R115.2, U103.3 (~RESET)
/N_U19_INM: C171.2, R133.2, TP503.1 (1_1), U19.4 (IN-)
/N_U19_INP: R44.2, R45.1, U19.3 (IN+), U108.1
/N_U19_OUT: C171.1, R48.1, R130.1, TP502.1 (1_1), U19.1 (OUT)
/N_U21_Flag: C65.1, D23.2 (A), R49.2, R55.1, TP521.1 (1_1), U21.8 (Flag), U107.8 (Flag)
/N_U21_P: R48.2, U21.3 (+)
/N_U21__: R56.1, R59.1, TP505.1 (1_1), U21.2 (-), U21.6
/N_U22_INP: R66.2, R67.2, R96.2, R134.1, TP513.1 (1_1), U22.3 (IN+)
/N_U22_OUT: C68.2, R79.1, U22.1 (OUT)
/N_U24_INP: R92.2, R94.2, U24.4 (IN-)
/N_U24_OUT: C76.2, R96.1, TP516.1 (1_1), U24.1 (OUT), U26.1
/N_U106_INM: R130.2, R131.1, U106.4 (IN-)
/N_U106_OUT: R131.2, R132.1, TP504.1 (1_1), U106.1 (OUT)
/N_U107_OUT: R57.1, R58.1, TP506.1 (1_1), U107.2 (-), U107.6
/N_U_TIA1_IN_: C_f1.1, R_f1.1, U_TIA1.2 (IN-)
/N_U_TIA2_IN_: C_f2.2, R_bias1.2, R_f2.1, U_TIA2.2 (IN-)
/PD_MON: C_f2.1, R_f2.2, U_TIA2.6 (OUT)
/TEC_BTF_N: R63.2, R76.2, TP510.1 (1_1)
/TEC_BTF_P: R65.1, R68.1, TP509.1 (1_1), U32.1 (-)
/TEC_EN: R121.1, TP520.1 (1_1), U103.7 (IO3), U108.6
/TEC_IMON_F: C120.1, R119.2, U102.5 (AIN1)
/VREF_DAC: C123.1, U101.1 (VREF)
/VZERO_SET: R41.2, R42.1, R43.2, TP526.1 (1_1), U17.3 (IN+)
/VZERO_TRIM: R43.1, R117.2
/unconnected-(U26-Pad8): U26.8
CLK10M_BUS: J1.c28
ERR: R92.1, U104.1
ERR1_BUS: J1.c20, U104.2
ERR2_BUS: J1.c22, U104.8
FAULT_n: J1.a24, U102.2 (ALERT), U103.13 (~INT)
GA0: JP101.1, R127.2, U101.12 (A0), U102.1 (ADDR), U103.1 (A0), U104.6, U105.6
GND: C65.2, C113.2, C114.2, C115.2, C116.2, C117.2, C118.2, C119.2, C120.2, C121.2, C122.2, C123.2, C130.2, C131.2, C132.2, C133.2, C134.2, C135.2, C136.2, C137.2, C138.2, C139.2, C140.2, C141.2, C142.2, C143.2, C144.2, C145.2, C146.2, C147.2, C148.2, C149.2, C150.2, C151.2, C152.2, C153.2, C154.2, C155.2, C156.2, C157.2, C158.2, C165.2, C166.2, C167.2, C168.2, C169.2, C170.2, C172.2, C173.2, C174.2, C175.2, C176.2, C177.2, C_NTC1.2, J1.a8, J1.a10, J1.a18, J1.a19, J1.a21, J1.a23, J1.a25, J1.a27, J1.a29, J1.b8, J1.b10, J1.b18, J1.b19, J1.b20, J1.b21, J1.b22, J1.b23, J1.b24, J1.b25, J1.b26, J1.b27, J1.b28, J1.b29, J1.b30, J1.b31, J1.b32, J1.c8, J1.c10, J1.c18, J1.c19, J1.c21, J1.c23, J1.c25, J1.c27, J1.c29, JP101.2, J_BTF1.6 (NC), R42.2, R49.1, R67.1, R70.1, R75.2, R78.1, R81.2, R120.2, R121.2, R122.2, R123.2, R124.2, R125.2, TP527.1 (1_1), TP528.1 (1_1), TP529.1 (1_1), TP530.1 (1_1), U26.3 (GND), U28.1 (-), U28.6 (Ref), U101.4 (GND), U101.9 (~LDAC), U101.14 (A1), U101.16 (RSTSEL), U102.3 (GND), U103.2 (A1), U103.6 (IO2), U103.8 (GND), U104.3 (GND), U105.3 (GND), U106.3 (IN+), U108.3 (GND), U_TIA1.4 (V-), U_TIA2.4 (V-)
HB_FAULT_LOC: R55.2, U103.5 (IO1)
LAS_IMON: R118.1, TP515.1 (1_1), U28.7
LOCK_EN: R120.1, TP522.1 (1_1), U26.6, U103.4 (IO0)
MOD1_BUS: J1.c24, U105.2
MOD2_BUS: J1.c26, U105.8
MOD_DRV: C66.1, U105.1
MPD_MON: C_f1.2, R_f1.2, TP518.1 (1_1), U102.6 (AIN2), U_TIA1.6 (OUT)
NTC_A: C_NTC1.1, R69.1, R_NTC1.2, TP519.1 (1_1), U102.7 (AIN3), U_TIA2.3 (IN+)
unnamed: R98.1, U28.2 (Rg)
unnamed: R98.2, U28.3 (Rg)
unnamed: R102.1, U32.2 (Rg)
unnamed: R102.2, U32.3 (Rg)
unnamed: R132.2, U107.3 (+)
PGND_TEC: C159.2, C160.2, C161.2, C162.2, C163.2, C164.2, J1.a3, J1.a4, J1.b3, J1.b4, J1.c3, J1.c4
SCL: R112.2, U101.13 (SCL), U102.10 (SCL), U103.14 (SCL)
SCL_BUS: J1.a28, R112.1
SDA: R111.2, U101.8 (SDA), U102.9 (SDA), U103.15 (SDA)
SDA_BUS: J1.a26, R111.1
SPARE_A30: J1.a30
SPARE_A31: J1.a31
SPARE_A32: J1.a32
SPARE_C30: J1.c30
SPARE_C31: J1.c31
SPARE_C32: J1.c32
TEC_IMON: R119.1, R133.1, TP511.1 (1_1), U32.7
TEC_VZERO: R45.2, TP501.1 (1_1), U17.1 (OUT), U17.4 (IN-), U32.6 (Ref), U108.2
VOUT_LAS: C113.1, R66.1, R113.2, TP512.1 (1_1)
VOUT_TEC: C114.1, R44.1, R114.2
VREF_MID: C166.1, J1.a22, TP523.1 (1_1), U24.3 (IN+)
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

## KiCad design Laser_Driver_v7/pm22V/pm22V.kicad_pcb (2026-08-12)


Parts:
C1, C2: 470nF; C_0805_2012Metric_Pad1.18x1.45mm_HandSolder
C3, C4, C9, C10: 2200uF 50V; CP_Radial_D18.0mm_P7.50mm
C5, C6: 1000uF 50V; CP_Radial_D16.0mm_P7.50mm
C7, C8: 2.2 uF; C_0805_2012Metric_Pad1.18x1.45mm_HandSolder
D1: GBPC1510W; Diode_Bridge_28.6x28.6x7.3mm_P18.0mm_P11.6mm; Manufacturer Part Number GBPC1510W; DigiKey P/N 2616-GBPC1510W-ND
D2, D3: 1N4742A; D_DO-41_SOD81_P10.16mm_Horizontal
HS1, HS2: Heatsink Boyd 531102B02500G; Heatsink_AAVID_Extruded_531102B02500G_34.9x12.7mm_H38.1mm
HS3: Heatsink Boyd 6223BG (GBPC); Bridge_GBPC_Heatsink_Boyd_6223BG
J5: Screw_Terminal_01x03; TerminalBlock_Phoenix_MKDS-1,5-3-5.08_1x03_P5.08mm_Horizont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; MPN 1729131
J6: DIN41612_03x32_C_Split; DIN41612_C_3x32_Male_Horizontal_THT
Q1: IRF540NPBF; TO-220-3_Vertical
Q2: IRF9540NPBF; TO-220-3_Vertical
R2, R3: 15; R_Axial_Power_L38.0mm_W9.0mm_P45.72mm
R4, R5: 1M; R_0805_2012Metric_Pad1.20x1.40mm_HandSolder
R6, R7: 100k; R_0805_2012Metric_Pad1.20x1.40mm_HandSolder
R8, R9: 0.47; R_1206_3216Metric_Pad1.30x1.75mm_HandSolder; MPN CRL1206-FW-R470ELF

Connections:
+18V: C5.1, C7.1, J6.a7, J6.b7, J6.c7, R8.2
+18Vac: D1.2, J5.3
-18V: C6.2, C8.2, J6.a9, J6.b9, J6.c9, R9.2
-18Vac: D1.3, J5.1
/+18VNF: C3.1, D3.2 (A), Q1.3 (S), R2.2, R4.2, R8.1
/-18VNF: C4.2, D2.1 (K), Q2.3 (S), R3.2, R5.1, R9.1
/RAW22+: C10.1, D1.1 (+), Q1.1 (D), R2.1, R6.1
/RAW22-: C9.2, D1.4 (-), Q2.1 (D), R3.1, R7.1
GND: C1.2, C2.2, C3.2, C4.1, C5.2, C6.1, C7.2, C8.1, C9.1, C10.2, J5.2, J6.a8, J6.a10, J6.b8, J6.b10, J6.c8, J6.c10
unnamed: C2.1, D2.2 (A), Q2.2 (G), R5.2, R7.2
unnamed: C1.1, D3.1 (K), Q1.2 (G), R4.1, R6.2

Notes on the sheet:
Electrolytic caps 35V rating
DIN 41612 BACKPLANE CONNECTOR (Type C, 96-way, 3x32 @ 2.54 mm): Board: Harting 09031966921 (right-angle male, 96-way, THT). Mate: Harting 09032966855 (vertical female, backplane side). Contacts rated 2 A; the pinout is designed at 1.5 A derated, with every rail owning whole a/b/c columns. See SLOT_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
In rush limiter / soft-start
14-15 ohm wire wound 10-15 W


Board: 2 copper layers, 160.0 x 100.0 mm, 28 parts (0 on the bottom side), 11 nets.

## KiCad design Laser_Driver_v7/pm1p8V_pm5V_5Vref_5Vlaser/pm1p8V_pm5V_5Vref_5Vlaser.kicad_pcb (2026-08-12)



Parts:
C9, C10, C14, C17, C18, C27, C35, C36, C37, C38, C55, C58, C72, C73, C74: 100nF; C_0805_2012Metric_Pad1.18x1.45mm_HandSolder; Manufacturer Part Number CL21B104KBCNNNC; DigiKey P/N 1276-1003-2-ND
C11, C56: 4.7uF; C_0805_2012Metric_Pad1.18x1.45mm_HandSolder; Manufacturer Part Number CL21B475KAFNNNE; DigiKey P/N 1276-2969-2-ND
C12, C21, C30, C31, C60, C67, C70: 4.7uF X7R; C_0805_2012Metric_Pad1.18x1.45mm_HandSolder; Manufacturer Part Number CL21B475KAFNNNE; DigiKey P/N 1276-2969-2-ND
C13: 10uF 25V X7R; C_1206_3216Metric_Pad1.33x1.80mm_HandSolder; Manufacturer Part Number C1206C106K3RACTU; DigiKey P/N 399-C1206C106K3RACTUCT-ND
C15, C28, C29, C65, C66, C68: 10uF; C_0805_2012Metric_Pad1.18x1.45mm_HandSolder; Manufacturer Part Number C0805C106K3PACTU; DigiKey P/N 399-11939-2-ND
C16: 10uF 16V Polymer; CP_EIA-3528-21_Kemet-B_HandSolder; Manufacturer Part Number T520B106M016ATE100; DigiKey P/N 399-5483-2-ND
C19: 47uF RC; C_1210_3225Metric_Pad1.33x2.70mm_HandSolder; Manufacturer Part Number TMK325ABJ476MM-P; DigiKey P/N 587-5479-2-ND
C20: 4.7uF RC; C_0805_2012Metric_Pad1.18x1.45mm_HandSolder; Manufacturer Part Number CL21B475KAFNNNE; DigiKey P/N 1276-2969-2-ND
C22: 10uF X5R or X7R; C_0805_2012Metric_Pad1.18x1.45mm_HandSolder; Manufacturer Part Number C0805C106K3PACTU; DigiKey P/N 399-11939-2-ND
C23, C24: 1uF; C_0805_2012Metric_Pad1.18x1.45mm_HandSolder; Manufacturer Part Number C0805C105K5RACTU; DigiKey P/N 399-C0805C105K5RACTUTR-ND
C25, C26, C54: 4.7uF 50V X7R; C_0805_2012Metric_Pad1.18x1.45mm_HandSolder; Manufacturer Part Number CGA4J1X7R1H475K125AC; DigiKey P/N 445-181404-1-ND
C32, C33, C34: 10uF 50V X7R; C_1210_3225Metric_Pad1.33x2.70mm_HandSolder; Manufacturer Part Number CL32B106KBJNNWE; DigiKey P/N 1276-3388-1-ND
C57, C63, C64: 0.33uF; C_0805_2012Metric_Pad1.18x1.45mm_HandSolder; Manufacturer Part Number CL21B334KBFNNNE; DigiKey P/N 1276-1123-2-ND
C59: 100uF; C_1210_3225Metric_Pad1.33x2.70mm_HandSolder; Manufacturer Part Number 1210YD107MAT2A; DigiKey P/N 478-11408-2-ND
C61, C62, C69, C71: 22uF 25V X7R; C_1210_3225Metric_Pad1.33x2.70mm_HandSolder; Manufacturer Part Number C1210C226M3RACTU; DigiKey P/N 399-C1210C226M3RACTUCT-ND
C75: 1uF; C_0805_2012Metric_Pad1.18x1.45mm_HandSolder; Manufacturer Part Number C0805C105K5RACTU; DigiKey P/N 399-C0805C105K5RACTU-ND
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

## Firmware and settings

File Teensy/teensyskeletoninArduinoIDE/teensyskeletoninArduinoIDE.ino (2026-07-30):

/* Dual-PDH Controller — Teensy 4.1   (Rev 2.0 — RF analog-derivative lock)
   Two independent frequency locks for 1550 nm DFB lasers.

   Rev 2.0: the lock-in demod (AD831) and PI servo are ANALOG hardware; the
   Teensy is a SUPERVISOR. Per channel it programs a DRIVE + a phase-set
   REFERENCE AD9833 (dual-Ω, phase-coherent via shared 25 MHz MCLK), sweeps the
   DC setpoint to acquire, hands the loop to the analog PI via LOCKn_EN
   (integrator hold/run), auto-calibrates the demod phase, and monitors the
   post-mix baseband error on LOCKn_IN. See TeensyFirmwareAssumptions.txt and
   docs/firmware_reference.html (Rev 2.0).

   Hardware : v5 DIG eurocard — CDCE913 clock, 4x AD9833 DDS (2 drive + 2 ref),
              ILI9341 320×240 TFT, built-in Ethernet (QNEthernet).
              Per CH card via the I2C backplane bus: AD5696R setpoint DAC,
              ADS1115 monitors, PCA9538 (LOCK_EN out / HB fault in).
              AFE card: AD831 demod + analog PI (ERRn_BUS analog to A10/A11),
              ADS1115 PD-level monitors. Shared open-drain FAULT_n on pin 31.
   Interfaces: USB-serial CLI | Ethernet Telnet CLI (port 23) | HTTP dashboard (port 80)

   Demo mode is a RUNTIME setting — no recompile needed:
     'demo on'   — switch to hardware simulation (Teensy + TFT only)
     'demo off'  — switch to real PDH hardware
   The setting persists in EEPROM across power cycles.
*/

#include <Arduino.h>
#include <Wire.h>
#include <SPI.h>
#include <FreqCount.h>
#include <Adafruit_GFX.h>
#include <Adafruit_ILI9341.h>

#include "config.h"
#include "cdce913.h"
#include "ad9833.h"
#include "chcard.h"
#include "pid.h"
#include "lock.h"
#include "display.h"
#include "comms.h"
#include "net_settings.h"
#include "network.h"
#include "demo.h"   // always compiled; only driven when g_demo_mode == true

// ============================================================
// Hardware
// ============================================================
// SPI1 hardware bus: MOSI=26, SCK=27 — explicit constructor required
Adafruit_ILI9341 tft(&SPI1, PIN_TFT_DC, PIN_TFT_CS, PIN_TFT_RST);

// ============================================================
// Control state
// ============================================================
LockChannel ch[2];

PID pid[2] = {
  {0.08f, 0.5f, 0.0f, 0.0f, 0.0f, -1.0f, 1.0f, 0.5f},
  {0.08f, 0.5f, 0.0f, 0.0f, 0.0f, -1.0f, 1.0f, 0.5f}
};

float g_dither_freq = DITHER_FREQ_HZ;   // legacy/JSON display (= CH1 Ω)

// Per-channel RF modulation frequency and demod (reference) phase.
float g_rf_omega[2] = { RF_OMEGA1_HZ, RF_OMEGA2_HZ };
float g_rf_phase[2] = { RF_PHASE1_DEG, RF_PHASE2_DEG };

// Runtime demo flag — loaded from EEPROM, toggled by 'demo on/off'
bool g_demo_mode = false;

elapsedMicros loopTimer;

// ============================================================
// Display model
// ============================================================
DispModel disp;

// ============================================================
// Real-hardware sensor values (always compiled; only used when
// g_demo_mode == false so they don't shadow the demo values)
// ============================================================
static float    s_err[2]     = {0.0f, 0.0f};
static float    s_laser_i[2] = {0.0f, 0.0f};
static float    s_tec_temp[2]= {NAN,  NAN};
static uint16_t s_dac[2]     = {DAC_MID_CODE, DAC_MID_CODE};
static float    s_rms_sum[2] = {0.0f, 0.0f};
static int      s_rms_cnt[2] = {0, 0};
static float    s_rms_val[2] = {0.5f, 0.5f};

// TEC current monitoring and software current limit
static float    s_tec_i[2]       = {0.0f, 0.0f};
static uint16_t s_tec_dac[2]     = {TEC_DAC_ZERO_CODE, TEC_DAC_ZERO_CODE}; // desired setpoint (default 0 A)
static float    s_tec_lim_fac[2] = {1.0f, 1.0f};                 // 1.0 = no limiting

// Normalised PDH error. Zero error is ERR_CENTER_V (= VREF_MID), NOT
// half the ADC range — the AFE output stage is referenced to the
// backplane mid rail. Scaled by the positive headroom so |e| = 1 at
// the point the ADC clips, and clamped so a far-off-resonance negative
// excursion (which has 3x more headroom) cannot skew err_rms.
static inline float adc_to_error(int raw) {
  float e = (raw - ERR_MID_COUNTS) / ERR_SPAN_COUNTS;
  if (e >  1.0f) e =  1.0f;
  if (e < -1.0f) e = -1.0f;
  return e;
}

// v5: monitors arrive as VOLTS from the per-card ADS1115s.
static inline float volts_to_tec_amps(float v) {
  if (isnan(v)) return 0.0f;
  return (v - TEC_IMON_OFFSET_V) / TEC_IMON_V_PER_A;
}

// Smoothly clamp the TEC setpoint DAC when current exceeds TEC_ILIMIT_A.
// s_tec_dac[i] holds the desired setpoint; this function derives the
// limited output and writes it to DAC channel 2+i each control tick.
static void tec_limit_step(int i) {
  if (s_tec_i[i] > TEC_ILIMIT_A) {
    s_tec_lim_fac[i] -= TEC_ILIMIT_STEP;
    if (s_tec_lim_fac[i] < 0.0f) s_tec_lim_fac[i] = 0.0f;
  } else {
    s_tec_lim_fac[i] += TEC_ILIMIT_RESTORE;
    if (s_tec_lim_fac[i] > 1.0f) s_tec_lim_fac[i] = 1.0f;
  }
  // Scale the excursion from zero-current code by the limit factor.
  // This preserves the direction (cooling or heating) while clamping magnitude.
  int32_t zero  = (int32_t)TEC_DAC_ZERO_CODE;
  int32_t raw   = (int32_t)s_tec_dac[i];
  int32_t delta = (int32_t)((raw - zero) * s_tec_lim_fac[i]);
  int32_t out   = constrain(zero + delta, 0, 65535);
  chcard_write_tec_dac(i, (uint16_t)out);   // cached: no I2C if unchanged
}

static float ntc_to_celsius(float v) {
  if (isnan(v) || v <= 0.0f || v >= NTC_VSUP) return NAN;
  float ratio = v / NTC_VSUP;
  float r = NTC_R_SERIES * ratio / (1.0f - ratio);
  float t_k = 1.0f / (1.0f / 298.15f + logf(r / NTC_R25) / NTC_BETA);
  return t_k - 273.15f;
}

static void update_disp_model() {
  for (int i = 0; i < 2; i++) {
    disp.state[i] = ch[i].state;

    if (s_rms_cnt[i] > 0) {
      s_rms_val[i] = sqrtf(s_rms_sum[i] / s_rms_cnt[i]);
      s_rms_sum[i] = 0.0f;
      s_rms_cnt[i] = 0;
    }

    if (ch[i].state == LOCK_SEARCH) {
      unsigned long elapsed = millis() - ch[i].state_ts;
      disp.ch[i].scan_phase = fmodf(elapsed / (float)SCAN_PERIOD_MS, 1.0f);
    }

    disp.ch[i].tec_temp_c   = s_tec_temp[i];
    disp.ch[i].laser_i_ma   = s_laser_i[i];
    disp.ch[i].tec_i_a      = s_tec_i[i];
    disp.ch[i].tec_lim_fac  = s_tec_lim_fac[i];
    disp.ch[i].setpoint_pct = s_dac[i] * 100.0f / 65535.0f;
    disp.ch[i].err_rms      = s_rms_val[i];

    if (ch[i].state == LOCK_LOCKED) {
      float q = 1.0f - s_rms_val[i] / ch[i].acquire_threshold;
      disp.ch[i].lock_qual = constrain(q, 0.0f, 1.0f);
    } else if (ch[i].state == LOCK_HOLD) {
      disp.ch[i].lock_qual = 0.5f;
    } else {
      disp.ch[i].lock_qual = 0.0f;
    }
  }
  disp.pll_lock   = cdce_pll_locked();
  disp.refclk_mhz = 25.0f;
}

// ============================================================
// RF analog-derivative lock — supervisor
//
// The lock-in demod (AD831) and PI servo are ANALOG. The Teensy:
//   • programs the drive + reference DDS (dual-Ω, phase-coherent),
//   • sweeps the DC setpoint (DAC) to drag the laser across resonance,
//   • on capture, RELEASES the analog integrator (LOCKn_EN = RUN) so the
//     analog PI holds the lock,
//   • monitors the post-mix baseband error (LOCKn_IN) and, optionally,
//     off-loads the analog integrator by trimming the DC setpoint.
// The digital PID is no longer the lock servo (pid[] is retained only for
// the legacy CLI/JSON and the optional centering gain).
// ============================================================

// Analog integrator: RUN (loop closed) / HOLD (acquiring). v5: via the
// CH card's PCA9538 IO0 — write-on-change, so calling every tick is free.
static inline void set_integrator(int i, bool run) {
  chcard_set_lock_en(i, run);
}

// Persist the current Ω / demod-phase to EEPROM (via net_settings) so they
// survive a power cycle. Cheap — EEPROM emulation only rewrites changed bytes.
static void persist_rf() {
  NetSettings ns;
  net_settings_load(ns);
  ns.rf_omega[0] = g_rf_omega[0];  ns.rf_omega[1] = g_rf_omega[1];
  ns.rf_phase[0] = g_rf_phase[0];  ns.rf_phase[1] = g_rf_phase[1];
  net_settings_save(ns);
}

// Reprogram one channel's drive+reference DDS at a new Ω, released together
// so the pair restarts phase-coherent. Preserves the calibrated demod phase.
void rf_set_omega(int i, float hz) {
  g_rf_omega[i] = hz;
  uint8_t drv = (i == 0) ? PIN_AD9833_1_CS : PIN_AD9833_2_CS;
  uint8_t ref = (i == 0) ? PIN_AD9833_3_CS : PIN_AD9833_4_CS;
  ad9833_load(drv, hz, REFCLK_HZ, 0.0f);
  ad9833_load(ref, hz, REFCLK_HZ, g_rf_phase[i]);
  ad9833_run(drv);  ad9833_run(ref);     // release back-to-back → coherent
  if (i == 0) g_dither_freq = hz;
  persist_rf();
}

// Live demod-phase update (reference DDS PHASE0).
void rf_set_phase(int i, float deg) {
  g_rf_phase[i] = deg;
  ad9833_set_phase(i == 0 ? PIN_AD9833_3_CS : PIN_AD9833_4_CS, deg);
  persist_rf();
}

// Demod-phase calibration: step the reference phase over 0–360° and pick the
// phase that maximises the discriminator signal. Park the laser so there is a
// non-zero error (e.g. on a resonance shoulder, or 'hold') before running.
void rf_phase_cal(int i, Print& out) {
  uint8_t ref_cs = (i == 0) ? PIN_AD9833_3_CS : PIN_AD9833_4_CS;
  uint8_t in_pin = (i == 0) ? PIN_LOCK1_IN    : PIN_LOCK2_IN;
  set_integrator(i, false);                 // hold while sweeping phase
  out.print(F("CH")); out.print(i + 1); out.println(F(" demod-phase calibration:"));
  float best_mag = -1.0f; int best_p = 0;
  for (int p = 0; p < 360; p += PHASE_CAL_STEP_DEG) {
    ad9833_set_phase(ref_cs, (float)p);
    delay(PHASE_CAL_SETTLE_MS);
    long acc = 0;
    for (int k = 0; k < PHASE_CAL_SAMPLES; k++) acc += analogRead(in_pin);
    float mean = (float)acc / PHASE_CAL_SAMPLES;
    float mag  = fabsf(mean - ERR_MID_COUNTS);   // discriminator size about VREF_MID
    out.print(F("  ")); out.print(p); out.print(F(" deg  |e|=")); out.println(mag, 1);
    if (mag > best_mag) { best_mag = mag; best_p = p; }
  }
  rf_set_phase(i, (float)best_p);
  out.print(F("CH")); out.print(i + 1);
  out.print(F(" demod phase -> ")); out.print(best_p); out.println(F(" deg (verify lock polarity)"));
}

// ============================================================
// AFE ERR offset null (AD5696R at 0x0E, replaces RV201/RV202)
//
// What gets nulled is the demodulator PEDESTAL — AD835 output offset
// plus LO->W feedthrough — which is present whenever the LO runs and
// there is no optical error signal. So the light MUST be blocked (or
// the laser parked well off resonance) before calibrating: with a real
// discriminator signal present this would null the signal itself and
// walk the lock point, which is exactly the failure mode the hardware
// injection resistors were sized to keep bounded.
// ============================================================
uint16_t g_err_null[2] = { AFE_NULL_CODE_MID, AFE_NULL_CODE_MID };

static void persist_err_null() {
  NetSettings ns;
  net_settings_load(ns);
  ns.err_null[0] = g_err_null[0];  ns.err_null[1] = g_err_null[1];
  net_settings_save(ns);
}

// Average the raw ERR ADC for this channel, after letting the VB node settle.
static float err_mean_counts(uint8_t pin) {
  delay(NULL_CAL_SETTLE_MS);
  long acc = 0;
  for (int k = 0; k < NULL_CAL_SAMPLES; k++) acc += analogRead(pin);
  return (float)acc / NULL_CAL_SAMPLES;
}

// Apply a null code by hand (bring-up / manual override).
void err_null_set(int i, uint16_t code) {
  g_err_null[i] = code;
  afe_write_null_dac(i, code);
  persist_err_null();
}

// 16-step successive approximation on the null DAC. ERR rises
// monotonically with code (VOUTA/B -> VB -> non-inverting DC path),
// so keep each trial bit whenever the reading is still at or below the
// 2.5 V target; that converges on the largest code with ERR <= target.
void err_null_cal(int i, Print& out) {
  uint8_t pin = (i == 0) ? PIN_LOCK1_IN : PIN_LOCK2_IN;

  if (ch[i].state == LOCK_LOCKED || ch[i].state == LOCK_ACQUIRE) {
    out.print(F("CH")); out.print(i + 1);
    out.println(F(" is locked/acquiring — run stopN or holdN first."));
    return;
  }
  if (!afe_null_present()) {
    out.println(F("AFE null DAC (0x0E) did not ACK — check the AFE card."));
    return;
  }

  set_integrator(i, false);                 // hold the analog servo throughout
  out.print(F("CH")); out.print(i + 1);
  out.println(F(" ERR offset null — BLOCK THE LIGHT (or park off resonance)."));

  // Confirm the pedestal is actually inside the DAC's authority before
  // searching; if it is not, SAR would silently converge on an endpoint.
  afe_write_null_dac(i, 0);
  float lo_v = err_mean_counts(pin);
  afe_write_null_dac(i, 0xFFFF);
  float hi_v = err_mean_counts(pin);
  out.print(F("  span: code 0 -> ")); out.print(lo_v, 1);
  out.print(F(" counts, code 65535 -> ")); out.print(hi_v, 1);
  out.print(F(" counts (target ")); out.print(ERR_MID_COUNTS, 1); out.println(F(")"));

  if (!(lo_v <= ERR_MID_COUNTS && hi_v >= ERR_MID_COUNTS)) {
    afe_write_null_dac(i, g_err_null[i]);   // leave the old code in place
    out.println(F("  FAILED: pedestal outside DAC range. Check LO drive, that the"));
    out.println(F("  light is blocked, and R141/R143 (8.25k) / R146/R147 (100k)."));
    return;
  }

  uint16_t code = 0;
  for (int b = 15; b >= 0; b--) {
    uint16_t trial = code | (uint16_t)(1u << b);
    afe_write_null_dac(i, trial);
    if (err_mean_counts(pin) <= ERR_MID_COUNTS) code = trial;
  }

  afe_write_null_dac(i, code);
  float resid = err_mean_counts(pin) - ERR_MID_COUNTS;
  g_err_null[i] = code;
  persist_err_null();

  out.print(F("CH")); out.print(i + 1);
  out.print(F(" null code -> ")); out.print(code);
  out.print(F("  residual ")); out.print(resid, 2); out.print(F(" counts ("));
  out.print(resid * (ADC_REF_V / ADC_MAX) * 1e3f, 2); out.println(F(" mV at ERR)"));
  if (fabsf(resid) > NULL_CAL_TOL_COUNTS)
    out.println(F("  WARNING: residual above tolerance — noisy input or drifting pedestal."));
  out.println(F("  Saved to EEPROM. Unblock the light before locking."));
}

// Optional slow integrator off-load (anti-windup). Trims the DC setpoint to
// absorb the analog-PI correction, keeping the analog integrator near centre.
// Requires the optional CORR taps (see config.h); otherwise a no-op.
static void center_step(int i) {
#ifdef PIN_LAS1_CORR_MON
  static uint16_t cnt[2] = {0, 0};
  if (++cnt[i] < 50) return;                 // ~20 Hz: far slower than the analog PI
  cnt[i] = 0;
  uint8_t pin = (i == 0) ? PIN_LAS1_CORR_MON : PIN_LAS2_CORR_MON;
  int corr = analogRead(pin) - ADC_MID;      // analog-PI output vs centre
  int32_t code = (int32_t)s_dac[i] - (corr >> 6);  // small step; sign per wiring — FLAG
  s_dac[i] = (uint16_t)constrain(code, 0, 65535);
  chcard_write_laser_dac(i, s_dac[i]);
#else
  (void)i;
#endif
}

// Per-channel acquisition state
static int       s_sweep_dir[2]  = {1, 1};
static bool      s_armed[2]      = {false, false};
static float     s_prev_e[2]     = {0.0f, 0.0f};
static LockState s_prev_state[2] = {LOCK_IDLE, LOCK_IDLE};

static void control_step(int i, float e, float dt) {
  (void)dt;
  // Hand the loop to / take it from the analog integrator by state.
  set_integrator(i, ch[i].state == LOCK_ACQUIRE || ch[i].state == LOCK_LOCKED);

  // State-entry hook
  if (ch[i].state != s_prev_state[i]) {
    if (ch[i].state == LOCK_SEARCH) s_armed[i] = false;
    s_prev_state[i] = ch[i].state;
  }

  switch (ch[i].state) {
    case LOCK_IDLE:
      break;

    case LOCK_SEARCH: {
      // Sweep the DC setpoint to drag the laser across resonance (bounce at rails).
      int32_t code = (int32_t)s_dac[i] + s_sweep_dir[i] * SWEEP_STEP_CODE;
      if      (code >= 65535) { code = 65535; s_sweep_dir[i] = -1; }
      else if (code <= 0)     { code = 0;     s_sweep_dir[i] =  1; }
      s_dac[i] = (uint16_t)code;
      chcard_write_laser_dac(i, s_dac[i]);   // ~90 µs I2C write; pre-lock, so noise-safe
      // Arm on a discriminator shoulder; capture the next zero-crossing (= resonance).
      if (fabsf(e) > ch[i].acquire_threshold) s_armed[i] = true;
      bool zero_cross = (e == 0.0f) || (e * s_prev_e[i] < 0.0f);
      if (s_armed[i] && zero_cross) {
        disp.ch[i].peak_phase = disp.ch[i].scan_phase;
        lock_enter(ch[i], LOCK_ACQUIRE);     // integrator released next tick
        Serial.print(F("CH")); Serial.print(i+1); Serial.println(F(" resonance -> ACQUIRE"));
      }
      break;
    }

    case LOCK_ACQUIRE:
      // Analog PI now closing the loop; DC setpoint held at the capture code.
      if (fabsf(e) < ch[i].lock_threshold) {
        ch[i].locked = true;
        lock_enter(ch[i], LOCK_LOCKED);
        Serial.print(F("CH")); Serial.print(i+1); Serial.println(F(" LOCKED"));
      } else if (millis() - ch[i].state_ts > ch[i].acquire_timeout_ms) {
        ch[i].relock_attempts++;
        lock_enter(ch[i], LOCK_RELOCK);
      }
      break;

    case LOCK_LOCKED:
      if (fabsf(e) > ch[i].acquire_threshold) {
        ch[i].locked = false;
        lock_enter(ch[i], LOCK_RELOCK);
        Serial.print(F("CH")); Serial.print(i+1); Serial.println(F(" LOCK LOST"));
      } else {
        center_step(i);                      // optional slow integrator off-load
      }
      break;

    case LOCK_HOLD:
      break;

    case LOCK_RELOCK:
      if (millis() - ch[i].state_ts > ch[i].relock_backoff_ms * (1 + ch[i].relock_attempts))
        lock_enter(ch[i], LOCK_SEARCH);
      break;
  }
  s_prev_e[i]   = e;
  s_rms_sum[i] += e * e;
  s_rms_cnt[i]++;
}

// ============================================================
// USB serial line buffer
// ============================================================
static String usb_line;
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
void loop() {

  // ---- USB serial (line-buffered) ----------------------------
  while (Serial.available()) {
    char c = (char)Serial.read();
    if (c == '\n' || c == '\r') {
      usb_line.trim();
      if (usb_line.length())
        comms_process(usb_line, Serial, ch, pid, disp);
      usb_line = "";
    } else {
      usb_line += c;
    }
  }

  // ---- 1 kHz control / simulation tick ----------------------
  if (loopTimer < CONTROL_PERIOD_US) return;
  float dt = loopTimer / 1e6f;
  loopTimer = 0;

  if (g_demo_mode) {
    // Demo: drive state machine and fill DispModel from simulation
    demo_update(ch, disp, dt);
  } else {
    // Real hardware. Fast path (1 kHz): analog error sampling only —
    // the slow monitors are I2C telemetry, refreshed in the 10 Hz tick.
    s_err[0] = adc_to_error(analogRead(PIN_LOCK1_IN));
    s_err[1] = adc_to_error(analogRead(PIN_LOCK2_IN));
    tec_limit_step(0);
    tec_limit_step(1);

    // Shared FAULT_n (open-drain wired-OR, active-low) is an ATTENTION signal
    // only — see hb_fault_update() for why it cannot be treated as a level.
    // React promptly to an assertion EDGE by identifying the source; the
    // latched per-card state comes from the 10 Hz level poll further down.
    bool line_low = (digitalRead(PIN_FAULT_N) == LOW);
    static bool prev_line_low = false;
    if (line_low && !prev_line_low) {
      bool fault0 = hb_fault_update(0);
      bool fault1 = hb_fault_update(1);
      if (!fault0 && !fault1)
        Serial.println(F("FAULT_n asserted by a non-CH card (check AFE/expander wiring)"));
    }
    prev_line_low = line_low;
    control_step(0, s_err[0], dt);
    control_step(1, s_err[1], dt);
  }

  // ---- 10 Hz display + network + I2C telemetry tick ----------
  static unsigned long last_disp = 0;
  if (millis() - last_disp >= DISPLAY_PERIOD_MS) {
    last_disp = millis();
    if (!g_demo_mode) {
      // Telemetry round robin (one ADS1115 channel per card per tick).
      // Noise rule: the bus stays quiet while a channel is acquiring.
      bool acquiring = (ch[0].state == LOCK_ACQUIRE) || (ch[1].state == LOCK_ACQUIRE);
      if (!acquiring) {
        chcard_poll(0);
        chcard_poll(1);
        afe_poll();
      }
      // H-bridge fault is a LEVEL on IO1, so it has to be polled. Deliberately
      // NOT gated on `acquiring`: this is one register read per card versus the
      // ADS1115 round robin's start+read, and an output stage in thermal
      // shutdown outranks the bus-quiet rule.
      hb_fault_update(0);
      hb_fault_update(1);
      for (int i = 0; i < 2; i++) {
        const ChCardMon& m = chcard_mon(i);
        s_laser_i[i]  = isnan(m.las_imon_v) ? 0.0f : m.las_imon_v * LASER_IMON_MA_PER_V;
        s_tec_temp[i] = ntc_to_celsius(m.ntc_v);
        s_tec_i[i]    = volts_to_tec_amps(m.tec_imon_v);
      }
      update_disp_model();  // demo fills disp each tick
    }
    display_update(tft, disp);
    network_poll(ch, pid, disp, disp.pll_lock, disp.refclk_mhz);
  }

  // ---- 1 Hz debug print -------------------------------------
  static unsigned long last_dbg = 0;
  if (millis() - last_dbg >= DEBUG_PERIOD_MS) {
    last_dbg = millis();
    if (g_demo_mode) Serial.print(F("[DEMO] "));
    for (int i = 0; i < 2; i++) {
      Serial.print(F("CH")); Serial.print(i+1);
      Serial.print(' '); Serial.print(lock_state_name(ch[i].state));
      Serial.print(F(" rms="));  Serial.print(disp.ch[i].err_rms, 5);
      if (!isnan(disp.ch[i].tec_temp_c)) {
        Serial.print(F(" T="));  Serial.print(disp.ch[i].tec_temp_c, 1);
      }
      Serial.print(F(" I="));   Serial.print(disp.ch[i].laser_i_ma, 1);
      Serial.print(F(" mA"));
      if (disp.hbridge_fault[i]) Serial.print(F(" *** H-BRIDGE FAULT ***"));
      Serial.println();
    }
    Serial.print(F("IP: ")); Serial.println(network_ip());
  }
}

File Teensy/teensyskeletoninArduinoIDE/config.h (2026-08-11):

#pragma once

// ============================================================
// DEMO MODE DEFAULT (first-boot only)
// Demo mode is now a runtime setting stored in EEPROM.
// Use the command  'demo on'  or  'demo off'  via USB serial,
// Telnet, or the web dashboard — no recompile required.
//
// This value is only written to EEPROM when the device boots
// with a blank or invalid EEPROM (first flash after firmware
// update). Change it here if you want demo OFF as the factory
// default. After the first boot it has no effect.
// ============================================================
#define DEMO_MODE_DEFAULT  1   // 1 = demo on, 0 = real hardware

// ============================================================
// Hardware pin mapping — Teensy 4.1 on the v5 DIG eurocard
// (universal DIN 41612 Type M backplane, one pinout per slot)
//
// SPI0 (pins 11/12/13): AD9833 x4 (2 drive DDS + 2 reference DDS)
// SPI1 (pins 26/27/39): ILI9341 TFT          (dedicated display bus)
// I2C0 (pins 18/19):    SYSTEM BUS — CDCE913 (on-card) + per-card
//                        AD5696R DAC / ADS1115 ADC / PCA9538 expander
//                        on the CH and AFE cards via backplane b18/b19.
//                        Teensy is the only master; pullups R112/R113
//                        (4.7k, Clock section) are the only bus pullups.
//
// v5 CHANGES vs the v3 single-board map:
//   AD5064 SPI DAC        -> REMOVED (per-CH-card AD5696R over I2C)
//   analog monitor inputs -> REMOVED (per-card ADS1115 over I2C)
//   LOCKn_EN GPIOs        -> REMOVED (PCA9538 IO0 on each CH card)
//   HBRIDGE_FAULT1/2      -> replaced by ONE shared open-drain FAULT_n
//   card addressing       -> ONE on-card jumper (JP101, fit=0); no
//                            slot straps, DIG enumerates by I2C probe
//   ERRn_BUS stays ANALOG on A10/A11 (1 kHz supervisor sampling)
//
// I2C NOISE RULES (see Backplane_Slots + AFE/CH sheets):
//   telemetry poll <= 10 Hz, round-robin, and NEVER while a channel
//   is in ACQUIRE. The bus is static between transactions.
// ============================================================

// --- I2C0 (system bus) --------------------------------------
#define PIN_SDA           18
#define PIN_SCL           19

// --- Card addressing (v7, 2026-08-09): ONE on-card jumper ---
// Each CH card self-addresses with JP101 alone (fitted = 0). It sets
// the I2C address LSB on all three chips AND picks the ERR/MOD bus
// pair, so a card is either ch1 or ch2 with nothing else to set.
// The backplane GA pins are unused and there is nothing to read.
// D14/D15/D16 (was A0/A1/A2) are therefore SPARE.

// --- Shared fault line (open-drain wired-OR, active-low) ----
// Any card may assert; source identified via that card's PCA9538.
// External 10k pullup R305 on the DIG card; internal pullup as backup.
#define PIN_FAULT_N       31   // was HBRIDGE_FAULT1

// ============================================================
// I2C address map (7-bit) — from the ONE CH-card address jumper:
//   ch1 card: JP101 FITTED  -> GA0 = 0 (ADG419 IN=0 -> S1 =
//   ERR1/MOD1, verified vs ADG419 datasheet truth table);
//   ch2 card: JP101 OPEN    -> GA0 = 1.
//   v7 deleted JP102/JP103: GA1 is tied to GND on-card (A1 = 0 was its
//   only legal setting) and GA2 is gone. GA0 is the whole card identity.
//   ADS1115 ADDR <- GA0; AD5696R base 00011|A1|A0 (verified vs
//   ADI Rev E ds); PCA9538 base 0x70|A1<<1|A0 with A1 = 0.  The AFE ADS1115
//   straps ADDR->SDA on-card (0x4A), outside the CH 0x48/0x49 range.
//   The AFE also carries its own AD5696R (ERR offset null) strapped
//   A1=VLOGIC, A0=GND -> 0x0E, i.e. the next code after CH1/CH2.
// ============================================================
#define I2C_CDCE913_ADDR     0x65          // fixed, on the DIG card
#define I2C_ADS1115_CH1      0x48          // CH laser-1 card (GA0 = 0, JP101 fitted)
#define I2C_ADS1115_CH2      0x49          // CH laser-2 card (GA0 = 1, JP101 open)
#define I2C_ADS1115_AFE      0x4A          // AFE card (ADDR -> SDA)
#define I2C_AD5696_CH1       0x0C          // base 0x0C | GA0
#define I2C_AD5696_CH2       0x0D
#define I2C_AD5696_AFE       0x0E          // AFE ERR offset-null DAC (A1=1, A0=0)
#define I2C_PCA9538_CH1      0x70          // base 0x70 | GA0  (A1 tied to GND)
#define I2C_PCA9538_CH2      0x71
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

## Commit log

2026-05-25 Power supplies past first check
    General design for power supply complete. Need to go through models and footprints for all components.
    [+-15V.kicad_sch, +-6V TEC.kicad_sch, 3p3V.kicad_sch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]
2026-05-26 More updates for the power supply
    H-bridge for TEC making sense. +/-6V supply now making sense with capacitor multiplier good for 3A per polarity.
    [+-6V TEC.kicad_sch, Mains to +-18V.kicad_sch, TEC Control.kicad_sch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]
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2026-05-27 Worked on completing Controls and Drivers and CLK.
    Laser and TEC drivers and controls now mostly complete. Added a Clock that runs off an internal 10 MHz or switches to external 10 MHz. Made minor changes elsewhere.
    [+-6V TEC.kicad_sch, Clock.kicad_sch, DFBLaser.kicad_sch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]
2026-05-27 Added DFB package sheet with pinout. Minor update
    [LaserPackage.kicad_sch, laser_driver_v3.kicad_sch]
2026-05-28 First full draft complete. Added Teensy pinout sheet.
    Used Copilot to generate firmware draft. ** Still need to: Recheck all specifications and pins, verify design with simulations, go through all footprints, create layout.
    [CDCE913_32-byteConfigArry.txt, Laser Control.kicad_sch, Readback.kicad_sch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]
2026-05-28 Ran Teensy 4.1 code through copilot. Added ILI9341.
    Teensy code compiles without error now.
    [CDCE913_32-byteConfigArry.txt]
2026-05-29 Renumbered schematics, corrections, power verified
    [+-15V.kicad_sch, +-6V TEC.kicad_sch, 3p3V.kicad_sch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]
2026-05-29 Update names, footprints, values, and created BOM
    Updated files names, foot prints, component values, parts.
    Assigned values from Digikey catalog.
    Created CSV BOMs for each schematic.
    Including a Power analysis now for all components.
    [3p3V.kicad_sch, 3p3V_BOM.csv.xlsx, 5V_Laser.kicad_sch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]
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2026-05-29 Clearing ERC errors. laying out components.
    [3p3V.kicad_sch, 5V_Laser.kicad_sch, 5Vref.kicad_sch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]
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2026-06-01 Update to teensy pinout and config. Working on PCB
    Improved pin selection on Teensy for better operation.
    Started working through the PCB from in the power input.
    Updating footprints and getting the layout organized.
    [3p3V.kicad_sch, 5V_Laser.kicad_sch, 5Vref.kicad_sch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]
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2026-06-03 Added separate xfrmer for 6V.
    Added inrush protection with NTC and increased capacitance to reduce ripple on 6V
    [3p3V.kicad_sch, 5V_Laser.kicad_sch, 5Vref.kicad_sch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]
2026-06-03 Changed xfrmers, paralled BJTs for cap multiplier
    Changed the transformers to more appropriate voltages.
    Made the BJTs for the cap multipliers in parallel to better handle the load.
    Simulated the output ripple for the 6V.
    Clarifying notes, removed LT1028 changed to OPA192 to match circuit as drawn.
    Changed divider values for the TEC_zero value to be 1.2 V as designed.
    [5V_Laser.kicad_sch, Clock.kicad_sch, DFBLaser.kicad_sch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]
2026-06-03 Many changes. Working through ERC.
    Main changes are for the grounds. I found the NETTIE function to tie the GND, DGND and AGND together at a specific point on the boud with a footprint even.
    Changed transformers one more time to be consistent for both.
    Updated footprints to be consistent and avoid power input/output errors with the ERC.
    [3p3V.kicad_sch, 5V_Laser.kicad_sch, 5Vref.kicad_sch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]
2026-06-03 Added software limit to TEC current, Hbridge Fault
    Software limit to TEC current. Monitors up to 2.5 A, then flags and reduces setting.
    Hbridge fault now wired to Teensy and software flags.
    [Teensy.kicad_sch]
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2026-06-04 Update documentation and Teensy Sketch -demo issue
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2026-06-05 Changed to an RF modulation
    Based on the uncertainty calculation, needed to change from a low frequency modulation to an RF modulation. This drive down the noise, but required a very different implentation. The modulation is limited to about 2 MHz. Much faster is at the limit of this hardware and would require significant increase in complexity and cost.
    [5Vref.kicad_sch, DFBLaser.kicad_sch, Laser_Control.kicad_sch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]
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2026-06-07 Split into a power and signal board.
    I think all footprints are now valid. Need to figure out the power connections between boards, currently just screw terminals for wire. I think a single multi-pin connector will work, but want to fin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
    [3p3V.kicad_sch, 5V_Laser.kicad_sch, 5Vref.kicad_sch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]
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2026-06-10 Power PCB lay out done with no DRC errors.
    [5Vref.kicad_sch, PowerConnector.kicad_sch, laser_driver_v3_Power.kicad_pcb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]
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2026-06-14 Fixed board after update and crash
    [5V Laser.kicad_sch, 5V_Laser.kicad_sch, 5_v_laser.kicad_sch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]
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2026-06-18 Switching to Eurocard layouts.
    First iteration on first card. Still need to define the pins for the backplane connector.
    [Mains_18V_TEC.kicad_pcb, Mains_18V_TEC.kicad_sch, Mains_18V_TEC_BOM.xlsx]
2026-06-19 Corrected card dimension now need to replace
    [Mains_18V_TEC.kicad_pcb, Mains_18V_TEC.kicad_sch]
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2026-07-02 Start work on pm6V version 5
    Working through schematic and footprints before layout.
    [pm6V.kicad_pcb, pm6V.kicad_sch]
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2026-07-12 Fixed PM22V bridge rectifier footprint.
    [pm22V.kicad_pcb]
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2026-07-15 Power cards should be done now.
    This should be the last power card. Need to do one last review, but routing seems to be good.
    [pm1p8V_pm5V_5Vref_5Vlaser.kicad_pcb, pm1p8V_pm5V_5Vref_5Vlaser.kicad_sch, pm1p8V_pm5V_5Vref_5Vlaser_BOM_digikey.xlsx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]
2026-07-15 Figured out remaining cards.
    Created backplane pcb. Should be ready to go to fab just need BOM. Layout matches standard for hole spacing.
    Updated Teensy code to match pinout and updated schematics.
    Changed DGND to TECGND for clarity.
    [Backplane_Slots.kicad_pcb, Backplane_Slots.kicad_sch, pm6V.kicad_pcb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]
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2026-07-21 Changed CH card to 6 layer. Added single pt grnd.
    CH card is now layed out cleanly with 6 layers.
    Added a single point connection with surge protection to the backplane.
    [Backplane_Slots.kicad_pcb, Backplane_Slots.kicad_sch, Backplane_Slots_BOM_digikey.xlsx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]
2026-07-22 Round 1 of digital card
    Schematic I think is complete. PCB is just started.
    [DIG_Card.kicad_pcb, DIG_Card.kicad_sch]
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2026-07-23 Working on digital card.
    Put a bunch of vias, but didn't set the net to GND. Need to make them all GND.
    [DIG_Card.kicad_pcb, DIG_Card.kicad_sch, laser_driver_v3_MASTER_BOM_PRICED.csv.xlsx]
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2026-07-23 Many updates to the digital PCB
    Made LO outs 50 ohm
    Added 100 ohm resistor to display LED
    Added 33 0hm resistors to clocks 2 and 3 to prevent ringing
    Fixed traces, no connects, etc.
    Added ground vias.
    [DIG_Card.kicad_pcb, DIG_Card.kicad_sch]
2026-07-24 Digital PCB improvements
    Added more decoupling caps and bulk caps. Layout for these done.
    Added test point pads to the schematic. Need to put these into the layout to make probing easy and clean.
    [DIG_Card.kicad_pcb, DIG_Card.kicad_sch]
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2026-07-26 Updates to manual, CH card and Digital card.
    CH card, U24 inputs were reversed.
    Dig card, diode d24 was found to be reversed. This prevented the external 10 MHz from doing anything. Also adjusted the threshold for the 10 MHz signal with a 10 Mohm resistor (R110).
    Updated BOMs.
    [CH_Card.kicad_pcb, CH_Card.kicad_sch, CH_Card_BOM_digikey.xlsx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]
2026-07-26 AFE card ready for review. Added DAC for error.
    The DAC will null the error offset. This was originally done with trim resistors. The automated system has been programmed into the teensy.
    [AFE_Card.kicad_pcb, AFE_Card.kicad_sch, AFE_Card_BOM_digikey.csv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]
2026-07-27 Corrected OPA192 pad error.
    [pm1p8V_pm5V_5Vref_5Vlaser.kicad_pcb, pm1p8V_pm5V_5Vref_5Vlaser.kicad_sch]
2026-07-27 AFE card work.
    Changed out TIA's and worked on routing. No errors now.
    [AFE_Card.kicad_pcb, AFE_Card.kicad_sch, AFE_Card_BOM_digikey.csv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]
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2026-07-30 Working on analog board.
    Change photodiodes to the correct model and connector. Made an adapter to allow the photodiode to be edge connect. Made the footprint for the edge connect photodiode. Updated estimates from capacitance and dark current specifications from photodiode. Updates to manual and firmware correspond to all changes.
    Moved libary of custom footprints to lib folder for easy finding.
    [AFE_Card.kicad_pcb, AFE_Card.kicad_sch, Bracket v5.f3d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]
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2026-07-31 updates to AFE, CH, DIG and pm1p8_pm5V_5Vlaser
    schematics and pcbs updated. They seem to be ready, but will take one more look with fresh eyes before ordering.
    [AFE_Card.kicad_pcb, AFE_Card.kicad_sch, CH_Card.kicad_pcb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]
2026-08-01 Learned the connector/pins were end of life.
    Changed to a standard 96 pin connector. Cheaper, less likely to not be obsolete in the near future. Need to rework all of the boards. I moved them all to version 7 for a clean break in the file history.
    [AC_Board.kicad_pcb, AC_Board.kicad_sch, AFE_Card.kicad_pcb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]
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
